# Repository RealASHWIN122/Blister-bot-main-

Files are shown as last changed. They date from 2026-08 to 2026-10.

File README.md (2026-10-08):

# Blister Bot 💊🤖: DIY Edge AI Automated Medicine Dispenser

We can see automated medicine dispensers ranging from simple timed plastic boxes to massive pharmacy robotics. When we generally talk about home dispensers, they usually require the user to manually pop out pills and load them into daily bins. But what if a robot could handle the original packaging directly?

In this project, we challenge ourselves to build a complex mechatronic system that combines rotational indexing with a Cartesian CNC movement to mechanically punch pills right out of their original foil blister packs. Instead of relying on cloud APIs, this robot is powered entirely by Local Edge AI to ensure patient privacy (HIPAA compliance), offline reliability, and low-latency mechanical targeting.

If you're wondering how to make a smart, AI-driven pill dispenser at home using an Arduino Uno Q, this build walks through the full process, from CNC kinematics to the conversational code.

---

## 💡 Motivation
What if you didn't have to manually strip pills from medicine packets every time you had a cold? What if elderly people in nursing homes and living alone at home could be safely monitored and assisted even when there is no one around? And what if all of this was hands-free and handled by speaking as if you were talking to a regular person—and to top it off, all offline, so your private talks remain strictly within your circle?

That's what the Blister Bot is all about.

Not only has AI become more capable, it has also become vastly more efficient. Now, small models that can run on an old laptop with no dedicated GPU can handle complex tasks including conversational chatbots, coding, character recognition, speech-to-text, and facial recognition. All of this opens up the possibilities of creating useful, intelligent devices without needing an internet connection.

Historically, the only limitation was lightweight, powerful, and cheap hardware. We were stuck using TinyML on classic boards like the ESP32 or Arduino Uno R4, which are ultimately just microcontrollers lacking the raw memory to hold complex workflows. Luckily, with the creation of the Arduino Uno Q and similar boards, we finally have the edge hardware to pull off these AI hardware projects without compromise.

---

## 🤖 What is the Blister Bot?
The Blister Bot is a prototype DIY automated medicine dispenser designed to securely manage, schedule, and dispense medication directly from standard foil/plastic blister packs. Unlike traditional automatic dispensers where you must manually extract each pill to load the machine, the Blister Bot takes the entire untouched blister pack. It utilizes a custom-built 3-axis mini CNC machine to scan, target, and plunge the pill out of its casing. 

Furthermore, the Blister Bot acts as an intelligent medical assistant. It features a fully conversational AI interface, allowing patients to simply talk to it. Before dispensing any medication, it uses facial recognition to authenticate the user, cross-referencing their identity with an internal SQLite database to prevent overdosing or dispensing to the wrong patient. All of this runs entirely offline on edge hardware.

---

## ✨ Key Advantages
* **Zero Prep Work:** Dispenses directly from original blister packs using a CNC punch, eliminating the tedious need to pre-sort pills into weekly bins.
* **100% Offline AI:** Uses miniaturized, local AI models (like Qwen 0.5B, Sherpa-ONNX, and Piper) to ensure medical data privacy and zero latency. Absolutely no internet connection is required.
* **Conversational Interface:** Talk to it naturally instead of navigating a complex touchscreen, app, or confusing buttons.
* **Biometric Security:** Prevents accidental or unauthorized overdoses by physically verifying the patient's face before cutting the foil.
* **Dual Monitoring Interfaces:** Both a physical Edge LCD terminal and an Appliance Flask Web UI for caregivers.

---

## 🧰 Components Required

| Parts Used | How Many Units Required | Purpose |
| :--- | :---: | :--- |
| **Arduino Uno Q** | 1 | The main brain. The quad-core Qualcomm side handles AI and web serving, while the ARM Cortex RTOS handles real-time motor control. |
| **ULN2003 Motor Drivers** | 3 | Drives the stepper motors based on GPIO signals from the Uno Q. |
| **28BYJ-48 Stepper Motors** | 3 | Controls the X, Y, and Z axes of the CNC gantry and the rotary wheel indexing. |
| **USB Webcams** | 2 | Camera 1 is for patient Facial Recognition. Camera 2 is for Pill Contour Detection. |
| **16.8V Battery Pack** | 1 | Main power supply for the entire robotic system. |
| **LM2596 Buck Converter** | 1 | Steps down the 16.8V battery voltage to a safe, dedicated 5V rail for the motors. |
| **Custom 3D Printed Parts** | 1 Set | Includes the `blissupport.stl` framing, CNC gantry, and the `medicinewheelstand.stl` rotary wheel. |

---

## ⚡ System Architecture

*(System Architecture Image Placeholder)*
> **Tip:** You can generate this system architecture block diagram using a tool like **Mermaid.js**, **Draw.io**, or **Lucidchart**.
System Architecture Placeholder

The Blister Bot relies on a highly integrated architecture split between logical AI processing and real-time physical actuation:

1. **Conversational LLM Interface 🗣️**
   When you approach the machine, it utilizes a local **Qwen 2.5 LLM (0.5 Billion parameters)** for reasoning.
   * **Listening:** Uses **Sherpa-ONNX** (fine-tuned on custom voice data) for fast, offline speech-to-text.
   * **Processing:** Evaluates commands against an internal SQLite medical schedule and ruleset.
   * **Speaking:** Replies verbally using **Piper** for high-quality text-to-speech.

2. **Facial Recognition Security 👤**
   To prevent unauthorized dispensing, the system requires biometric authentication.
   * Your medical profile is securely stored using an **LBPH (Local Binary Pattern Histogram)** face recognizer.
   * Authentication must pass before the physical CNC actuates.

3. **Automated Pill Extraction ⚙️**
   * Camera 2 takes a snapshot of the blister pack.
   * **OpenCV contour detection** and **Meta's SAM 2 (Segment Anything Model 2)** locate the exact boundaries of the pill.
   * The software calculates a "Mirror Math" coordinate transformation.

---

## 🔌 Circuit Diagram

*(Circuit Diagram Image Placeholder)*
> **Tip:** You can generate professional circuit schematics using tools like **Fritzing**, **KiCad**, or **Tinkercad**.
Circuit Diagram Placeholder

### Power Isolation
To prevent inductive voltage spikes from the stepper motors from browning out or frying the logic board, the system uses an isolated power design. The 16.8V battery pack is connected to an **LM2596 buck converter** to supply a dedicated 5V rail strictly for the ULN2003 drivers and stepper motors. The Arduino Uno Q is powered safely on its own separated circuit.

---

## 📐 3D Printing & Mechanical Design

The mechanical chassis is built around a Cartesian CNC coordinate system paired with a rotary axis.
* **The Rotary Wheel (`medicinewheelstand.stl`):** Holds the foil blister packs. It indexes rotationally to bring the correct medicine pack to the cutting area. The 28BYJ-48 stepper motor is geared to provide high torque for rotating the heavy loaded wheel.
* **The CNC Gantry:** Actuates on the back of the packet to trace, plunge, and drill the pill out of the foil using a specialized punch tool. The gantry relies on dual X/Y rails.
* **The Frame (`blissupport.stl`):** Houses the cameras at fixed focal lengths to ensure OpenCV contour mathematics are consistently accurate.

---

## 💻 Deep Dive: Core AI Capabilities & Software Modules

Because the machine runs offline, memory management on the Uno Q is critical. The state machine (`master_controller.py`) orchestrates loading and unloading AI models dynamically so we don't run out of RAM.

### 1. Dual Interface System
The bot provides two main ways to interact, designed for both patients and caregivers:
* **Appliance Terminal:** A Flask web UI running on port 5000 that allows caregivers to view the live MJPEG camera feed, monitor system logs, and manually trigger HTTP voice commands.
* **Edge Terminal:** A lightweight serial-based interface (`main_edge_terminal.py`) that uses `faster-whisper` for ultra-low latency STT and outputs the AI's responses to a physical LCD screen via a serial bridge connected to the microcontroller's UART port (`/dev/ttyGS0`).

### 2. Fast Audio Processing (STT/TTS)
The voice pipeline is heavily optimized for the embedded CPU of the Arduino Uno Q:
* **Faster-Whisper:** We use the `tiny.en` model with `INT8` quantization via CTranslate2. This allows for 1:1 real-time transcription (a 5-second voice clip transcribes in ~5 seconds).
* **Hardware Resampling:** To prevent "hallucination" bugs common in Whisper when fed distorted audio, we strictly use ALSA hardware resampling (`plughw:0,0`) to convert the USB microphone's native sample rate perfectly to 16000Hz.
* **Edge-TTS & Piper:** For speech synthesis, we rely on low-latency TTS engines that generate human-like voices and play them back instantly via `ffplay`.

### 3. Intelligent Medicine Scanner & RAG
* **Medicine Scanner (OCR):** The appliance terminal uses `rapidocr-onnxruntime` to continuously monitor the camera feed, extract text from medicine packets, and announce the names aloud.
* **Retrieval-Augmented Generation (RAG):** When you ask for medication, the Qwen LLM queries an internal `medical_database.json` to verify schedules, dosages, and interactions before dispensing. This prevents patients from asking for restricted medications at the wrong time.

### 4. Facial Recognition & Security
To ensure medication is dispensed exclusively to the prescribed patient:
* We utilize the **LBPH (Local Binary Pattern Histogram)** recognizer from `opencv-contrib-python-headless`.
* During inference, it cross-references the detected face against a trained dataset of known faces.
* Every dispense event and interaction is strictly logged to an encrypted local SQLite database (`attendance.db`).

### 5. Mirror Math Kinematics & SAM 2 Vision
Locating the pill is a complex physical-to-digital translation problem. 
By looking at the clear plastic bubbles on the front of the packet, Camera 2 takes a snapshot. We use **Meta's Segment Anything Model 2 (SAM 2)** combined with OpenCV to accurately detect the boundaries of the blister. 

The Python script applies a scaling factor to convert pixels to millimeters, and then applies a **Mirror Math** formula to tell the rear-mounted CNC plunger exactly where to strike on the back of the packet:
```python
# The camera looks at the front, but the CNC punch attacks from the rear.
# The X-axis must be inverted for perfect alignment.
X_plunger = X_cam * -1
```

### The Full AI Pipeline
1. **Audio Trigger:** Captured via USB mic (filtered by Voice Activity Detection).
2. **STT:** Transcribes audio to text offline.
3. **LLM & RAG:** Processes intent (e.g. "I need paracetamol") against the medical database.
4. **Face ID:** Verifies the user against `attendance.db` via OpenCV.
5. **Vision:** Targets the pill boundaries using SAM 2.
6. **CNC Drive:** Pulses the stepper motors to mechanically punch the pill.
7. **TTS:** Announces "Your medication is dispensed."

---

## 🛠 Setup & Installation Guide

Setting up the Blister Bot environment locally on the board requires installing a few core edge-AI dependencies:

### Prerequisites
Make sure your Arduino Uno Q is running its Debian Linux image and is connected to Wi-Fi for the initial download phase.
```bash
sudo apt update
sudo apt install python3-pip python3-opencv ffmpeg portaudio19-dev libasound-dev
```

### Model Installations
Install the specialized Edge AI models required for the system to operate:
```bash
pip3 install faster-whisper edge-tts rapidocr-onnxruntime Flask pyserial sounddevice
pip3 install git+https://github.com/facebookresearch/sam2.git
```

### Flashing the Real-Time OS
Remember that the high-level Python code runs on the Qualcomm Quad-Core. You must compile and flash the Arduino `C++` stepper motor code to the ARM Cortex side of the board so that it can receive instructions over the serial bridge from the `cnc_driver.py`.

---

## 📁 Repository Structure

All project files, drivers, and AI scripts are contained within the main repository.

```text
📦 blister-bot
 ┣ 📂 appliance_terminal/          # Flask Web UI, OCR Scanner & HTTP mic triggers
 ┣ 📂 edge_terminal/               # Serial LCD interface & faster-whisper STT
 ┣ 📂 code/
 ┃ ┣ 📜 master_controller.py       # Main state machine & orchestrator
 ┃ ┣ 📜 cnc_driver.py              # Kinematics & tool offsets
 ┃ ┣ 📜 test_stt.py                # Automated testing for finetuned STT
 ┃ ┣ 📜 test_rag.py                # RAG database evaluation scripts
 ┃ ┣ 📜 medical_database.json      # RAG inventory and patient rules
 ┃ ┣ 📜 attendance.db              # SQLite logs for Face ID
 ┃ ┣ 📂 blister_detector/          # Meta SAM 2 vision bounding box scripts
 ┃ ┗ 📂 ai_modules/           
 ┃   ┣ 📜 face_id.py               # LBPH Face Recognizer
 ┃   ┣ 📜 vision.py                # OpenCV contour detection & SAM 
 ┃   ┗ 📜 conversational.py        # Qwen, Sherpa, and Piper loops
 ┣ 📂 scripts/
 ┃ ┣ 📜 deploy_master.sh           # Automated deployment scripts
 ┃ ┗ 📜 rsync.exp                  # Edge syncing
 ┣ 📂 cad/                         # 3D printable STL files
 ┣ 📂 docs/                        # Weekly progress logs
 ┗ 📜 README.md
```

---

## 🎯 Testing & Final Result

*(Video/GIF Placeholder)*
Final Result Video Placeholder

Once completely assembled, the Blister Bot operates entirely hands-free. A patient simply requests their medicine, looks into the primary camera, and waits. The machine indexes the wheel, lines up the CNC plunger, and perfectly extracts the pill directly from the foil without any human intervention.

---

## 🚀 Running the Bot

To start the Blister Bot system on the Arduino Uno Q, navigate to the `code/` directory and run the main state machine script:
```bash
cd code/
python3 master_controller.py
```

*Note: Alternatively, you can use the `scripts/deploy_master.sh` script to set up `systemd` services so the bot runs automatically on boot.*

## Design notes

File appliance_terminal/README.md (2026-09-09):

# Blister-Bot Appliance Terminal

The Appliance Terminal is a Flask-based AI system designed to run on the **Arduino Uno Q**. It transforms the board into an intelligent medicine-scanning assistant featuring Optical Character Recognition (OCR), Face Recognition, and an ultra-fast Voice Assistant (Speech-to-Text & Text-to-Speech).

## Core Features

### 1. Medicine Scanner (OCR)
- Uses `rapidocr-onnxruntime` to continuously monitor the camera feed.
- Extracts text dynamically from medicine packets and displays the detected text on the web interface.
- Automatically reads the detected medicine names out loud using the TTS engine.

### 2. Lightning-Fast Voice Assistant (STT & TTS)
The voice pipeline was heavily optimized for the embedded CPU of the Arduino Uno Q:
- **Speech-to-Text (STT)**: 
  - Upgraded from HuggingFace `transformers` to **`faster-whisper`** (powered by `CTranslate2`).
  - Uses `INT8` quantization and the `tiny.en` model to achieve blistering fast **1:1 real-time transcription** (a 5-second voice clip transcribes in ~5 seconds).
  - Implements **ALSA hardware resampling** (`plughw:0,0`) to perfectly convert the USB microphone's native sample rate to the strictly required `16000Hz`. This completely eliminates the "hallucinations" (random ghost phrases) that Whisper models often produce when fed distorted audio.
  - Automatically filters out silence using `faster-whisper`'s advanced Voice Activity Detection (VAD).
- **Text-to-Speech (TTS)**:
  - Uses `edge-tts` to generate natural-sounding speech and `ffplay` to play it immediately through the audio output.
  - The appliance automatically repeats what you say when the microphone is manually triggered, and reads out scanned text.

### 3. Face Recognition & Attendance
- Utilizes OpenCV (`opencv-contrib-python-headless`) with Haar cascades and the `LBPHFaceRecognizer`.
- Detects faces and cross-references them against a trained dataset (`known_faces`).
- Logs attendance and interactions to a local SQLite database (`attendance.db`).

### 4. Flask Web Interface
- The entire system is hosted locally via Flask on port `5000`.
- Serves the live camera feed (MJPEG streaming).
- Provides a `/trigger_mic` REST endpoint to manually initiate a 5-second voice recording and transcription.

## Deployment & Setup

The system is deployed to the Arduino Uno Q using the `setup_appliance.sh` script located in the project root. The setup script performs the following fully automated tasks:

1. **Space Management**: Cleans up unused files (e.g., old Ollama models) on the board's filesystem.
2. **File Transfer**: Uses `scp` to push `appliance.py`, the `attendance.db`, and the face datasets directly to the board.
3. **Dependency Installation**: Installs the optimized dependency stack globally (`--break-system-packages`) including `faster-whisper`, `rapidocr-onnxruntime`, `Flask`, `edge-tts`, and `opencv`.
4. **Systemd Service**: Creates and enables `appliance.service` so the AI terminal automatically starts silently in the background on boot.

## How to Test the Microphone
1. Ensure the board is powered and connected to the network.
2. Open the web interface at `http://<ARDUINO_IP>:5000`.
3. Wait ~10 seconds for the `faster-whisper` model to silently load in the background.
4. Click the **"🎤 Speak"** button, talk into the USB mic for 5 seconds, and watch the text appear on the screen and echo back to you.

## Recent Migrations
- **Migrated away from `transformers`**: Swapping to `faster-whisper` reduced STT processing time by an order of magnitude. An attempt to use `base.en` was made, but the 45-second latency was unacceptable for a voice assistant. Reverting to `tiny.en` within `faster-whisper` solved all latency issues while maintaining VAD accuracy.
- **ALSA `plughw` fix**: Swapped `hw:0,0` for `plughw:0,0` in the `arecord` command to allow the Linux kernel to handle audio resampling, preventing severe Whisper hallucination bugs.

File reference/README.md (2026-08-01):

# Week 1: Intelligent Edge-AI Medicine Dispenser ("Blister Bot")






Welcome to the **Week 1** repository module for **Blister Bot** (Intelligent Edge-AI Medicine Dispenser). This directory contains all technical specifications, 3D CAD/Blender models, interactive WebGL 3D web applications, MP4 video animation demonstrations, Python vision mappers, C++ STM32 MCU firmware sketches, and publication-ready PDF documentation reports generated during Week 1.

---

## 📌 Executive Project Summary

**Blister Bot** is an autonomous, fully offline healthcare dispenser. Unlike conventional pill organizers that require manual sorting into plastic compartments or cloud dependence, Blister Bot operates as an edge-AI healthcare assistant built on the dual-processor **Arduino UNO Q** board (Qualcomm Dragonwing QRB2210 Linux MPU + STM32U585 MCU).

### Core Innovation: Non-Destructive Deblistering
Rather than high-force mechanical punching that crushes fragile pills, Blister Bot utilizes a two-stage mechanism:
1. **270-Degree U-Shaped Foil Scoring**: A motorized rotary cutter wheel scores a 270° U-shaped arc through the aluminum foil backing, creating a hinged flap while leaving the top 90° edge connected.
2. **Soft Silicone Plunger Pin Ejection**: A spring-loaded silicone plunger pin gently pushes against the transparent front PVC bubble, guiding the capsule tablet out through the pre-scored flap into the delivery chute.

---

## 📂 Week 1 File Navigation & Directory Structure

```
Week 1/
├── README.md                             # Navigation guide for GitHub repository (this file)
├── Project Blueprint.pdf                 # Original technical specification document
├── blueprint_text.txt                    # Plaintext extraction of Project Blueprint PDF
├── Week1_Documentation.md               # Main Week 1 technical markdown documentation
├── Week1_Documentation.pdf               # Publication-ready PDF documentation report (2.98 MB)
├── generate_pdf_report.py                # Python script to compile Week1_Documentation.pdf
│
├── blister_bot.blend                     # Native 3D Blender model file for complete Blister Bot
├── create_blister_bot_model.py           # Blender Python script generating full 3D appliance & renders
│
├── frames/                               # Extracted visual reference frames from reference video
│   ├── frame_000.jpg ... frame_009.jpg
│
├── renders/                              # High-resolution rendered 3D preview images
│   ├── render_perspective.png            # Studio isometric view
│   ├── render_mechanism.png              # Internal 2-axis CNC gantry close-up
│   └── render_front.png                  # Front presentation view
│
├── scoring mechanism/                    # Horizontal Scoring & Ejection Mechanism Module
│   ├── 3d_cutting_animation.html         # Interactive 3D WebGL (Three.js) animation web app
│   ├── scoring_mechanism_demo.mp4        # 120-frame MP4 video animation demonstration
│   ├── scoring_mechanism.blend           # Specialized Blender 3D kinematic model file
│   ├── Scoring_Mechanism_Report.pdf      # Dedicated PDF technical report (4.61 MB)
│   ├── Scoring_Mechanism_DeepDive.md     # Markdown technical deep-dive report
│   ├── deblister_vision_mapper.py        # Python front-to-back coordinate transformation & U-trajectory mapper
│   ├── scoring_gantry_controller.ino     # STM32 C++ firmware sketch for 2-axis CNC stepper & plunger
│   ├── animate_scoring_mechanism.py      # Blender Python animation generator
│   ├── compile_scoring_video.py          # Blender PNG frame renderer
│   ├── encode_mp4.py                     # OpenCV MP4 video encoder
│   ├── scoring_toolhead.png              # Still render preview (Step 1)
│   ├── u_flap_scored.png                 # Still render preview (Step 2)
│   └── tablet_ejection.png               # Still render preview (Step 3)
│
└── vertical scoring mechanism/           # Vertical Strip Plunger Ejection Mechanism Module
    ├── vertical_strip_plunger_animation.html # Interactive 3D WebGL (Three.js) animation web app
    ├── vertical_strip_ejection_demo.mp4   # 120-frame MP4 video animation demonstration
    ├── vertical_scoring_mechanism.blend   # Specialized Blender 3D model file (vertical strip orientation)
    ├── Vertical_Scoring_Report.pdf        # Dedicated PDF technical report (1.79 MB)
    ├── animate_vertical_scoring.py        # Blender Python animation generator
    ├── encode_vertical_mp4.py             # OpenCV MP4 video encoder
    ├── generate_vertical_pdf.py           # Python script compiling Vertical_Scoring_Report.pdf
    ├── vertical_strip_toolhead.png        # Still render preview (Phase 1)
    ├── vertical_u_flap.png               # Still render preview (Phase 3)
    └── vertical_plunger_eject.png         # Still render preview (Phase 5)
```

---

## 🚀 Key Modules & How to Use Them

### 1. Interactive 3D WebGL Web Applications (No Blender Required!)
Experience realistic 3D animations directly inside any web browser with orbit controls, step-by-step kinematic phase controls, X-Ray mode, and live telemetry:

- **Horizontal Scoring App**: Open `scoring mechanism/3d_cutting_animation.html` in your web browser.
- **Vertical Strip Plunger App**: Open `vertical scoring mechanism/vertical_strip_plunger_animation.html` in your web browser.

### 2. Video Demonstrations (MP4 Renders)
- **Horizontal Scoring Demo**: `scoring mechanism/scoring_mechanism_demo.mp4`
- **Vertical Strip Plunger Demo**: `vertical scoring mechanism/vertical_strip_ejection_demo.mp4`

### 3. PDF Documentation Reports
- **Week 1 Master Report**: `Week1_Documentation.pdf` (2.98 MB)
- **Horizontal Mechanism Deep-Dive**: `scoring mechanism/Scoring_Mechanism_Report.pdf` (4.61 MB)
- **Vertical Mechanism Deep-Dive**: `vertical scoring mechanism/Vertical_Scoring_Report.pdf` (1.79 MB)

### 4. Software & Firmware Source Code
- **Python Vision Coordinate Mapper**: `scoring mechanism/deblister_vision_mapper.py`  
  *Transforms camera pixel coordinates \((X_{\text{pixel}}, Y_{\text{pixel}})\) to rear aluminum foil gantry space \((X_{\text{gantry}}, Y_{\text{gantry}})\) and calculates 270° U-trajectory waypoints with dynamic safety clearance buffers (\(R_{\text{cut}} = R_{\text{pill}} + 2.0\text{mm}\)).*
- **STM32 Microcontroller Firmware**: `scoring mechanism/scoring_gantry_controller.ino`  
  *Arduino C++ sketch driving X/Y stepper motors smoothly via `AccelStepper`, engaging the rotary cutter wheel solenoid, actuating the silicone plunger pin, and verifying tablet drop via IR optic sensors.*

### 5. Blender 3D CAD & Kinematic Models
To open or re-render 3D models in Blender 5.2 LTS:
```bash
# Re-create and render full Blister Bot appliance model
blender --background --python create_blister_bot_model.py

# Re-create and render horizontal scoring mechanism
blender --background --python "scoring mechanism/compile_scoring_video.py"

# Re-create and render vertical strip mechanism
blender --background --python "vertical scoring mechanism/animate_vertical_scoring.py"
```

---

## 🛠️ Technology Stack & Dependencies

| Tool / Library | Version / Domain | Purpose |
| :--- | :--- | :--- |
| **Blender** | 5.2.0 LTS | 3D CAD modeling, PBR shading, studio lighting, camera tracking, and animation. |
| **Three.js** | r128 (WebGL) | Interactive 3D web application rendering, PBR materials, orbit controls, spark effects. |
| **Python** | 3.13 | Vision mapping mathematics, coordinate transformation, OpenCV video encoding, PDF report building. |
| **OpenCV (`cv2`)** | 4.x | Video frame sequence assembly and MP4 encoding. |
| **ReportLab** | 5.0.0 | Programmatic PDF document compilation with custom styling, tables, and images. |
| **Arduino C++** | STM32 Core | Real-time non-blocking stepper motor control (`AccelStepper.h`) and solenoid actuation. |

---

## 📄 License & Attribution

This project is part of the **Blister Bot** open-hardware healthcare initiative. All 3D models, code, firmware sketches, and documentation in this folder are prepared for open community research and development.

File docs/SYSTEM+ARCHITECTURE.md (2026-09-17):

when the arduino uno q boots up,it first has to search if its connected to all the necessary devices(cams,mic) and also check bluetooth(the speaker for the llm output tts),Then,it needs to use the speaker to say"hi,im awake."

once that happens,if the bot is being used for the first time,the user has to say "bot,setup",in order to start setting up users.the device then outputs "phone or voice" through the speaker(tts),and waits for the users reply("phone or voice")

if phone:
........

if voice:
device asks to define caretakers,each caretaker needs a name,and a time of work(morning,evening,full day),and if the caretaker itself is the patient.facial scanning and adding to the database will be done in parallel using cam1
if the last sentence is false:
after defining each caretaker,the device will ask if the list of caretakers is over,to which the user has to reply yes or no.
if no ,this repeats

if the last sentence is true,skip to patient definition,then go back to the caretaker loop

after the caretaker process is done,the device outputs:"enter patient name:",and waits for the users reply.also scans their face to store in the database
and also asks for age,gender,health issues,medicines to take along with their time(morning/evening,before food/after food),caretaker assigned to which the user can either reply in one word answers or can respond in a couple of sentences,whose meaning and relevant data will be extracted by the llm,and then sqlite tables will be created for everyone
.device asks if there are more patients,user replies yes/no
if yes,repeat
if no,break

this ends part1 of setup mode

in part2 of setup mode
the user has to insert the meds,after the user verbally confirms that all the meds have been inserted,the device uses cam 2 to scan each med text to dermine med name,dosage etc.it will have a separate table containing info related to mediicnes,so it will cross check it with this if its either unable to read the ocr small text or just to double check.the count of each medicines will also be stored alongisde

this ends setup mode

normal running mode:
after setup mode has been finished,the device will work normally.it will speak and alert the users using the speaker to alert people when they have to take their medicines.when the user walks in front of the camera or speaks near the mic,the facial recognition tool will work and scan the user to see if its a previously established user.if its a patient,the device will ask if they have had food (if they have special post food meds) and the same for if they have pre food meds.if they havent had food,then the device will them to eat their food and come back.if its a caretaker,they will be asked about whuch patient they are attending for,and the steps proceed as above.Once the conditions are met,the mediicnes are cut and dispensed using the motors.the wheel isrorated until the correct med comes in view,cam 2 is used to identify where the boundaries need to be drawn using the sam2 model,and then the motors are drawn along these boundaries.first the z motor or thrusting motor is thrust into the boundary,and then the xy gantry is used to create a hole arounf the med.then,the med holder is rotated by exactly enough degrees so that the cut med is facing the ground and it falls off.repeat if there are other meds.
update the med counter for all the meds,if n(one specific med)=1,alert user using speaker,and store reminder and alert the next dispensing timeslot right before dispensing the medicines

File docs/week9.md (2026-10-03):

# Week 9: Speech-to-Text Customization & RAG Integration

During Week 9 (Sep 22 - Sep 28), we focused heavily on resolving the poor performance of the baseline STT model and began prototyping LLM RAG functionality.

## Accomplishments
- **Custom STT Dataset Collection**: Built a full Flask-based web application (`code/stt_dataset_collector/app.py`) to systematically record, manage, and label custom audio phrases.
- **Catastrophic Forgetting Mitigation**: Successfully fine-tuned the Zipformer STT model on 91 custom audio samples using the `icefall` framework. To prevent the model from collapsing (catastrophic forgetting), we strategically froze the acoustic encoder and only trained the decoder and joiner.
- **STT Evaluation**: Automated STT evaluation metrics with `test_stt.py`, confirming massive improvements in recognizing specific medical intents (e.g., "what medicines do we have").
- **LLM RAG Pipeline**: Integrated Retrieval-Augmented Generation capabilities into `master_controller.py`, allowing the Qwen LLM to query and answer questions about patients and inventory. Built and tested this via `code/test_rag.py` and `code/test_rag_auto.py`.
- **Qualcomm AI Hub / Deployment**: Set up compilation scripts (`compile_qwen_aihub.py`) for optimized hardware inference and moved automated deployment shell scripts into `scripts/` to keep the repo clean.

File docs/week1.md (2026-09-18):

# Week 1: Initial Mechanical Design & Ideation

During Week 1 (July 28 - Aug 3), we laid the groundwork for the mechanical operation of the Blister Bot.

## Accomplishments
- Explored 3D models and animations to visualize how a machine could automatically punch a pill out of a blister pack.
- Documented initial CAD and scoring ideas.
- Designed early iterations of the scoring mechanisms (cutting the foil before plunging).

All historical files from Week 1 (Blender models, animations, old reports) are archived in [reference/week1/](../reference/week1/).

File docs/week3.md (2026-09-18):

# Week 3: Face Recognition & Arduino Preparations

During Week 3 (Aug 11 - Aug 17), we began exploring how to physically control our bot, alongside experiments with adding facial recognition for patient security.

## Accomplishments
- **Arduino Setup**: Started the initial Arduino firmware logic to interact with motors.
- **Face Recognition**: Explored basic LBPH face recognition for patients using `facerecogjith`.
- **Database Setup**: Initialized the SQLite database schemas to hold attendance and patient medical details.

All historical files from Week 3 are archived in [reference/week3/](../reference/week3/).

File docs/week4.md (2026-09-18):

# Week 4: Edge AI Prototyping

During Week 4 (Aug 18 - Aug 24), we explored numerous AI models in isolation to determine what would be viable on our edge computing device (Uno Q).

## Accomplishments
- **OCR Modules**: Evaluated text extraction mechanisms for reading blister pack labels.
- **Speech Models**: Built `texttospeech` and `speechtotext` standalone scripts to test offline inference speeds.
- **Action Recognition**: Tested the Edge Impulse action recognition platform (`action-recog-applab`).
- **Hardware Inspiration**: Sourced and reviewed the `Arduino mini CNC plotter` project as a mechanical base for our drilling mechanism.

All historical files from Week 4 are archived in [reference/week4/](../reference/week4/).

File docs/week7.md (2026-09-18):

# Week 7: Architecture Integration

During Week 7 (Sep 8 - Sep 14), we began integrating our standalone hardware tests and web apps into a cohesive software architecture.

## Accomplishments
- **CNC Controller**: Built the `stepper_motor_controller` Flask app and the underlying Arduino logic to handle web-based 3-axis control.
- **Remote Tooling**: Implemented `ssh_cmd.py`, `sync.py`, and `monitor_viewer.py` to seamlessly deploy code to our remote Uno Q board.
- **Hardware Finalization**: Produced the first versions of our finalized `.stl` files for the physical structure of the bot.

Deprecated tests, temporary Streamlit apps, and intermediate deployment scripts from Week 7/8 are archived in [reference/week7_8/](../reference/week7_8/). All finalized tooling is stored in `code/`.

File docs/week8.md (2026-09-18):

# Week 8: Master Controller & Final System

During Week 8 (Sep 15 - Sep 21), we brought everything together to form the autonomous Blister Bot.

## Accomplishments
- **Master Controller**: Developed `master_controller.py`, which integrates our offline LLM (Qwen), Speech-to-Text (Sherpa-ONNX), Text-to-Speech (Piper), and OpenCV Pill detection.
- **Dynamic CNC Integration**: Merged the CNC controller so the bot can verbally request pills, visually detect their boundary contours, and instruct the gantry to physically pierce and trace the boundary to extract them.
- **Final Hardware Architecture**: Finalized the remaining CAD support files (like `blissupport.stl` and `medicinewheelstand.stl`) which are stored directly in the root `cad/` directory.

The finalized, working system is contained entirely inside the `code/` folder.

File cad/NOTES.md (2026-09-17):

# Packet paddle wheel

- Single integrated rotor; Z is the hub axis. Four blades repeat at 90°.
- Blade length 95 mm parallel to Z; base thickness exactly 3 mm. Outer blade width 68 mm includes two 2 mm rail walls, with exactly 64 mm between the internal vertical walls.
- Each centered rectangular window is 50 × 80 mm, through the base. Centering leaves 7.5 mm flush end borders. The loading-end border is not raised and does not block axial sliding; an entirely absent entry border would require an additional notch or a non-centered/open-ended window.
- Loading is from Z=0 toward the raised stop at Z=93–95 mm. Each pair of inward-facing channels has 2 mm retaining lips and 3.5 mm clearance above the base; top opening between lips is 60 mm. No raised transverse loading-end obstruction.
- Assumed hub Ø20 × 97 mm (Z=-1 to 96 mm), rail height 5 mm above base, wall thickness 2 mm, lip thickness 1.5 mm.
- Socket: nominal Ø5 mm circle truncated at X=1.5 mm (4 mm from flat to opposite circular extreme); blind depth 12 mm from Z=-1. No fit allowance added. Verify flat and clearance against the actual motor shaft before fabrication.
- Rectangle profiles share a dimension-driven helper function because the same construction repeats at differing sizes. Its sketches are not point-and-click editable; dimensions remain editable in source.
- Validation: all seven evaluated solver sketches fully constrained; lint passed; rendered overview and close-ups verified windows, guide entrances, stops, and D-shaped cavity.

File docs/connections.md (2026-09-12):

# CNC Plotter Hardware Connections

This document details the complete hardware wiring between the Arduino Uno Q, the breadboard, the stepper motor drivers, and the power supply.

## 1. Breadboard & Power Supply Connections
> [!WARNING]
> Never power the stepper motors directly from the Arduino Uno Q's 5V pin! They draw too much current and will damage the board.

* **External Power Supply (+):** Connect the positive wire from your isolated 6V (4x AA) battery pack to the positive (red) rail on the breadboard.
* **External Power Supply (- / GND):** Connect the negative wire from your 6V (4x AA) battery pack to the negative (blue/black) rail on the breadboard.
* **Arduino Uno Q GND:** Connect a wire from any `GND` pin on the Arduino Uno Q to the negative (blue/black) rail on the breadboard. **This common ground is critical.**

## 2. Stepper Motor Drivers (e.g., ULN2003)
Each of the 3 motors requires its own driver board. 

### Powering the Drivers:
For **all three** drivers (X, Y, and Z):
* Connect the **`+` or `VCC`** pin on the driver to the positive rail on the breadboard.
* Connect the **`-` or `GND`** pin on the driver to the negative rail on the breadboard.

### Plugging in the Motors:
* Plug the white plastic connector coming from the X-Axis stepper motor directly into the white socket on the X-Axis driver board.
* Plug the Y-Axis stepper motor into the Y-Axis driver board socket.
* Plug the Z-Axis stepper motor into the Z-Axis driver board socket.

---

## 3. Arduino Data Connections (IN1, IN2, IN3, IN4)

Connect the logic pins from the Arduino Uno Q to the inputs on each respective driver board:

### X-Axis Motor Driver (Stepper 1)
* **IN1** $\rightarrow$ Arduino Pin `2`
* **IN2** $\rightarrow$ Arduino Pin `3`
* **IN3** $\rightarrow$ Arduino Pin `4`
* **IN4** $\rightarrow$ Arduino Pin `5`

### Y-Axis Motor Driver (Stepper 2)
* **IN1** $\rightarrow$ Arduino Pin `6`
* **IN2** $\rightarrow$ Arduino Pin `7`
* **IN3** $\rightarrow$ Arduino Pin `8`
* **IN4** $\rightarrow$ Arduino Pin `9`

### Z-Axis Motor Driver (Stepper 3)
* **IN1** $\rightarrow$ Arduino Pin `10`
* **IN2** $\rightarrow$ Arduino Pin `11`
* **IN3** $\rightarrow$ Arduino Pin `12`
* **IN4** $\rightarrow$ Arduino Pin `13`

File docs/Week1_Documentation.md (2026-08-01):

# Week 1 Documentation: Intelligent Edge-AI Medicine Dispenser ("Blister Bot")

## 1. Executive Summary & Project Vision

The **Intelligent Edge-AI Medicine Dispenser ("Blister Bot")** is an autonomous, fully offline healthcare system. Unlike conventional pill organizers that require tedious manual sorting or cloud connectivity, Blister Bot operates as an intelligent healthcare assistant. It directly interprets written prescriptions via computer vision (OCR), converses naturally with patients via a localized Large Language Model (LLM), prevents accidental overdoses, and **mechanically extracts medications directly from uncut aluminum blister strips**.

---

## 2. Hardware Architecture & Technical Specifications

The system is built upon the dual-processor architecture of the **Arduino UNO Q** (Qualcomm Dragonwing QRB2210 + STM32U585 MCU):

| Subsystem Component | Hardware / Software | Primary Responsibilities |
| :--- | :--- | :--- |
| **Linux MPU** | Qualcomm Dragonwing QRB2210 | Localized LLM (`llama.cpp` + `TinyLlama`), Voice STT (`Whisper.cpp`), Prescription OCR, Face Recognition, Action Tracking (`MediaPipe`), Database management. |
| **Microcontroller (MCU)** | STM32U585 MCU | Real-time 2-axis CNC gantry motor control (`AccelStepper`), sensor monitoring, safety interlocks, and closed-loop dispensing verification. |
| **Smart Interface** | 7" Portrait TFT/LCD Touchscreen | Displays pill schedules, visual dosage cross-checks, consumption graphs, and system telemetry. |
| **Vision Sensor** | Integrated HD Camera Module | Patient face recognition authentication, pill identification, prescription scanning, and hand-to-mouth action verification. |

---

## 3. Visual Reference Breakdown (From Video Reference)

Analysis of the reference video (`WhatsApp Video 2026-07-20 at 10.29.20 PM.mp4`) revealed the core architectural and mechanical design parameters:

````carousel
![Reference Frame 002: Dual Chamber & Smart Touch Display](file:///c:/FARIS/Blister%20Bot/Blister-bot-main-/Week%201/frames/frame_002.jpg)
<!-- slide -->
![Reference Frame 005: Internal Deblistering CNC Gantry & U-Scoring](file:///c:/FARIS/Blister%20Bot/Blister-bot-main-/Week%201/frames/frame_005.jpg)
<!-- slide -->
![Reference Frame 008: Appliance Presentation Overview](file:///c:/FARIS/Blister%20Bot/Blister-bot-main-/Week%201/frames/frame_008.jpg)
````

### Key Design Insights Extracted:
1. **Dual-Chamber Enclosure**: Left side houses illuminated internal mechanical components behind a transparent acrylic door; right side features the smart touch interface, AI camera, and dispensing tray.
2. **2-Axis CNC Deblistering Gantry**: Precision X/Y motion system carrying a specialized toolhead with a motorized 270-degree rotary cutter wheel and soft silicone plunger.
3. **U-Shaped Scoring Mechanics**: Rather than high-force punching which damages fragile tablets, the tool scores a 270-degree hinged flap in the aluminum foil backing, allowing a soft plunger to push the pill into the chute.

---

## 4. Week 1 3D Model Development & Blender Implementation

A complete, fully detailed 3D model of Blister Bot was procedurally created in **Blender 5.2 LTS** using a Python script (`create_blister_bot_model.py`).

### 3D Render Gallery

```carousel
![3D Render: Isometric Perspective Studio View](file:///c:/FARIS/Blister%20Bot/Blister-bot-main-/Week%201/renders/render_perspective.png)
<!-- slide -->
![3D Render: Deblistering Mechanism Close-Up](file:///c:/FARIS/Blister%20Bot/Blister-bot-main-/Week%201/renders/render_mechanism.png)
<!-- slide -->
![3D Render: Front Presentation View](file:///c:/FARIS/Blister%20Bot/Blister-bot-main-/Week%201/renders/render_front.png)
```

---

## 5. Summary of Built Components in 3D Model

1. **Appliance Body**:
   - Curved-corner desktop enclosure in matte white ABS plastic with dark metallic accents.
   - Hollowed-out left cavity equipped with warm top LED light strip (`Mat_LED_Warm`) and cyan vertical status light bar (`Mat_LED_Cyan`).
   - Beveled acrylic transparent front window door with metallic handle.

2. **Smart Touch Display & Vision Module**:
   - 7" portrait display screen with customized UI overlay (header bar, blister schedule card, action button).
   - Top camera module housing with optical ring and glass lens.
   - Lower RGB LED status indicator bar and sliding pill collection drawer.

3. **Core Deblistering Mechanics**:
   - **Blister Pack Rack**: Multi-slot holder containing aluminum foil cards, transparent PVC bubble pockets, and dual-tone blue/white capsules (`Mat_Pill_Blue`, `Mat_Pill_White`).
   - **2-Axis CNC Gantry**: Upper/lower X aluminum extrusions, vertical Y lead screw, guide rod, and dual NEMA 17 stepper motors (`Mat_Stepper_Body`).
   - **Scoring & Plunger Toolhead**: Motorized rotary steel cutter disc and spring-loaded silicone plunger pin positioned above the funneled delivery chute.

---

## 6. Week 1 Deliverables & File Directory Structure

All files created during Week 1 are organized cleanly in the `Week 1` directory:

```
c:/FARIS/Blister Bot/Blister-bot-main-/
├── LICENSE
├── README.md
└── Week 1/
    ├── Project Blueprint.pdf          # Full technical requirements specification
    ├── WhatsApp Video 2026-07-20...   # Video reference file
    ├── blueprint_text.txt             # Extracted text from PDF blueprint
    ├── create_blister_bot_model.py    # Python procedural 3D model generator for Blender 5.2
    ├── blister_bot.blend              # Native Blender 3D project model file
    ├── Week1_Documentation.md         # Comprehensive documentation report
    ├── frames/                        # Extracted reference frames (frame_000.jpg - frame_009.jpg)
    └── renders/                       # High-resolution rendered 3D preview images
        ├── render_perspective.png
        ├── render_mechanism.png
        └── render_front.png
```

---

## 7. Next Steps & Week 2 Roadmap

1. **Kinematic Animation in Blender**: Animate the 2-axis gantry movement, rotary cutter U-scoring path, and plunger ejection sequence.
2. **CAD Model Refinement**: Export 3D components to STL/STEP formats for parametric 3D printing tolerance checks.
3. **App Lab Firmware Integration**: Prototype basic STM32 C++ motor sketches using `AccelStepper` and Python RPC state machine logic.

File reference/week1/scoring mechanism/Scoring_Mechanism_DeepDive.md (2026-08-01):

# Deep Dive Technical Documentation: Strip Scoring & Tablet Ejection Mechanism

## 1. Overview & Mechanical Philosophy

In conventional automated pill dispensers, medication extraction relies on high-force mechanical punching through uncut blister packs. This brute-force approach frequently causes fragile tablets (e.g., uncoated aspirin, sublingual wafers, or softgel capsules) to fracture, crumble, or burst.

**Blister Bot** solves this through a non-destructive two-stage mechanism:
1. **270-Degree U-Shaped Foil Scoring**: A motorized rotary cutter wheel scores a 270° U-shaped arc through the opaque aluminum foil backing, creating a hinged flap while leaving the top edge connected.
2. **Soft Silicone Plunger Ejection**: A spring-loaded silicone plunger pin gently pushes against the transparent front PVC bubble, guiding the tablet out through the pre-scored foil flap without touching or scratching the medication.

---

## 2. Step-by-Step Kinematic Sequence

```mermaid
flowchart TD
    A["Camera Scans Transparent Front Bubble (X_pixel, Y_pixel)"] --> B["Front-to-Back Coordinate Transformation (X_gantry, Y_gantry)"]
    B --> C["Calculate 270° U-Scoring Path (R_cut = R_pill + 2.0mm)"]
    C --> D["2-Axis CNC Gantry Moves Toolhead to Approach Corner P1"]
    D --> E["Engage Motorized Rotary Cutter Wheel onto Foil"]
    E --> F["Execute U-Path Scoring: P1 -> P2 -> P3 -> P4"]
    F --> G["Disengage Cutter Wheel (270° Hinged Flap Opened)"]
    G --> H["Position Soft Silicone Plunger Pin over Pill Center"]
    H --> I["Extend Plunger 12mm to Push Tablet Through Flap"]
    I --> J["Closed-Loop Optic Beam Break Verification in Delivery Chute"]
```

---

## 3. Mathematical Coordinate & Clearance Equations

### Front-to-Back Coordinate Transformation
The front camera observes transparent PVC bubbles in image pixel space. The transformation to rear aluminum gantry millimeter coordinates is given by:

\[X_{\text{gantry}} = (X_{\text{pixel}} \times S_x) + O_x\]
\[Y_{\text{gantry}} = (Y_{\text{pixel}} \times S_y) + O_y\]

Where:
- \(S_x, S_y\): Scale calibration factors (\(\approx 0.45\text{ mm/pixel}\))
- \(O_x, O_y\): Physical offset between camera optical center and gantry home origin

### Dynamic Safety Clearance Margin
To guarantee the rotary cutter blade never comes into physical contact with the medication:

\[R_{\text{cut}} = R_{\text{pill}} + \Delta_{\text{safety}}\]

Where \(\Delta_{\text{safety}} = 2.0\text{ mm}\).

### 270-Degree U-Flap Trajectory Waypoints
For a target pill centered at \((X_c, Y_c)\), the cutter traverses the following four waypoints:
1. **P1 (Top-Left Approach)**: \((X_c - R_{\text{cut}}, Y_c + R_{\text{cut}})\)
2. **P2 (Bottom-Left Corner)**: \((X_c - R_{\text{cut}}, Y_c - R_{\text{cut}})\)
3. **P3 (Bottom-Right Corner)**: \((X_c + R_{\text{cut}}, Y_c - R_{\text{cut}})\)
4. **P4 (Top-Right Corner)**: \((X_c + R_{\text{cut}}, Y_c + R_{\text{cut}})\)

*The top horizontal segment between P4 and P1 remains un-cut (90° open angle), forming the flexible aluminum hinge.*

---

## 4. Hardware & Software Component Integration

| Component | Role in Scoring & Ejection | Implementation |
| :--- | :--- | :--- |
| **Rotary Cutter Wheel** | 270-degree foil scoring | Motorized dark steel cutting disc driven by gantry toolhead |
| **Silicone Plunger Pin** | Gentle tablet ejection | Soft orange silicone pin actuated by 12mm stroke solenoid |
| **2-Axis CNC Gantry** | X/Y motion positioning | NEMA 17 steppers driven by STM32 MCU (`AccelStepper.h`) |
| **Vision Mapper** | Target coordinate calculation | Python module (`deblister_vision_mapper.py`) |
| **Firmware Controller** | Real-time motion execution | Arduino C++ sketch (`scoring_gantry_controller.ino`) |
| **3D Kinematic Model** | Visual simulation & validation | Blender 5.2 model (`scoring_mechanism.blend`) |
| **Video Demonstration** | Animated sequence breakdown | MP4 video render (`scoring_mechanism_demo.mp4`) |

---

## 5. File & Asset Directory (`scoring mechanism/`)

```
c:/FARIS/Blister Bot/Blister-bot-main-/Week 1/scoring mechanism/
├── deblister_vision_mapper.py       # Python coordinate transformer & U-trajectory mapper
├── scoring_gantry_controller.ino    # STM32 C++ firmware sketch for CNC gantry & plunger
├── animate_scoring_mechanism.py     # Blender 5.2 Python script generating 3D model & video
├── scoring_mechanism.blend          # Specialized Blender 3D model file
├── scoring_mechanism_demo.mp4       # Rendered MP4 animation video sequence
├── Scoring_Mechanism_DeepDive.md    # Technical deep-dive documentation (this file)
├── Scoring_Mechanism_Report.pdf     # Publication-ready PDF document report
├── scoring_toolhead.png             # Frame 25: Toolhead approach render
├── u_flap_scored.png                # Frame 80: 270° U-flap scored render
└── tablet_ejection.png              # Frame 105: Soft plunger tablet ejection render
```

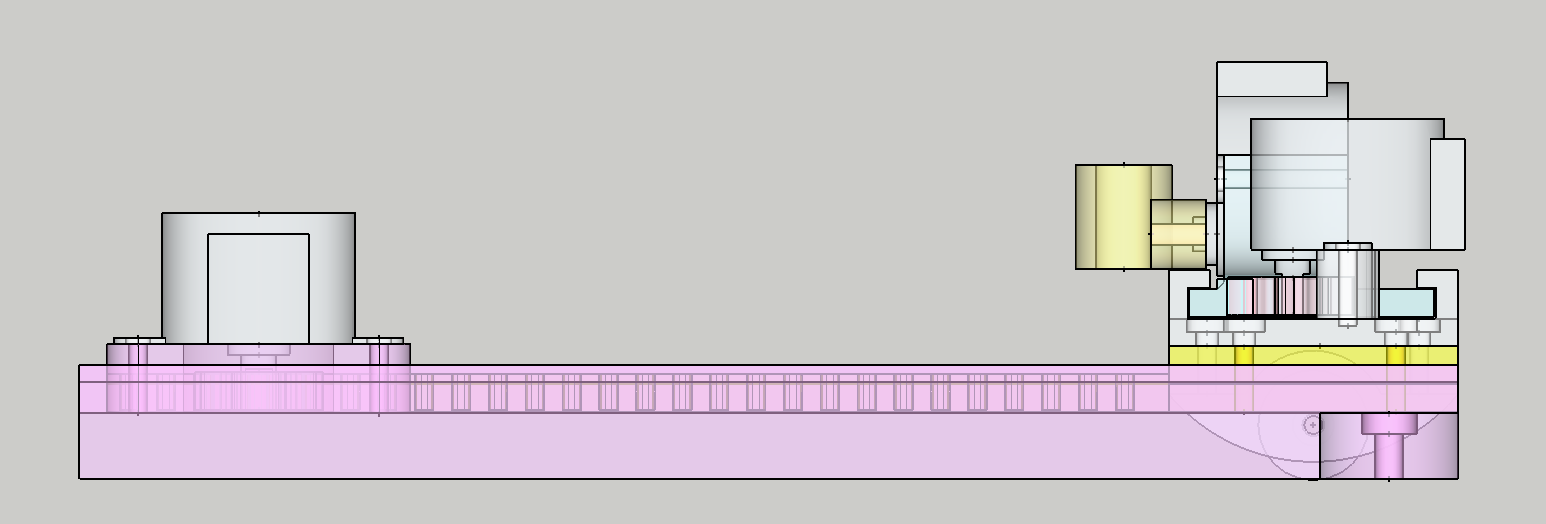
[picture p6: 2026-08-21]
reference/week4/Arduino mini CNC plotter - 4607077/images/Screen_Shot_2020-09-26_at_20.14.03.png

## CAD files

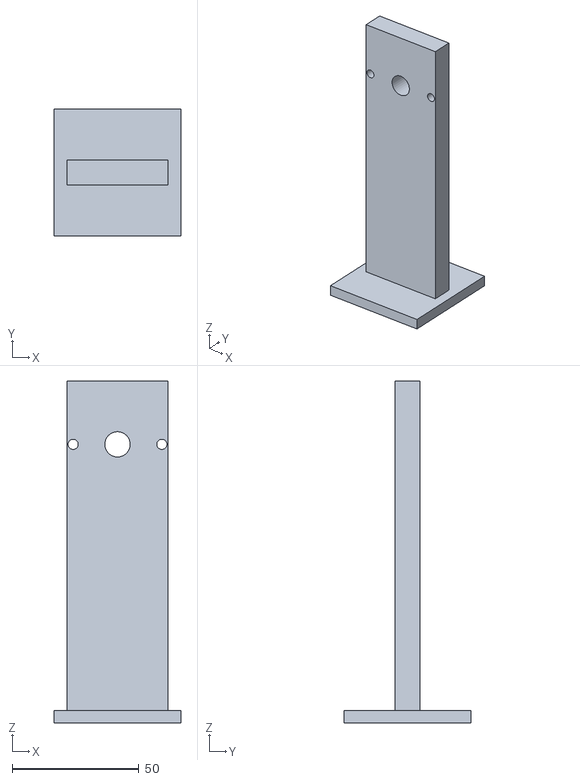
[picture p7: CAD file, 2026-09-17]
cad/medicinewheelstand.stl
50.0 x 50.0 x 135.0

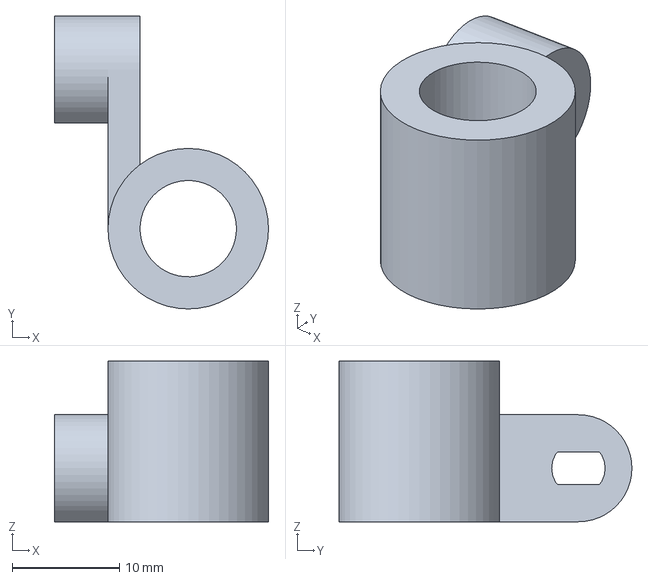
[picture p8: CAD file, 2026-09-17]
reference/week4/Arduino mini CNC plotter - 4607077/files/Unnamed7.FCStd
20.0 x 27.4 x 15.0 mm

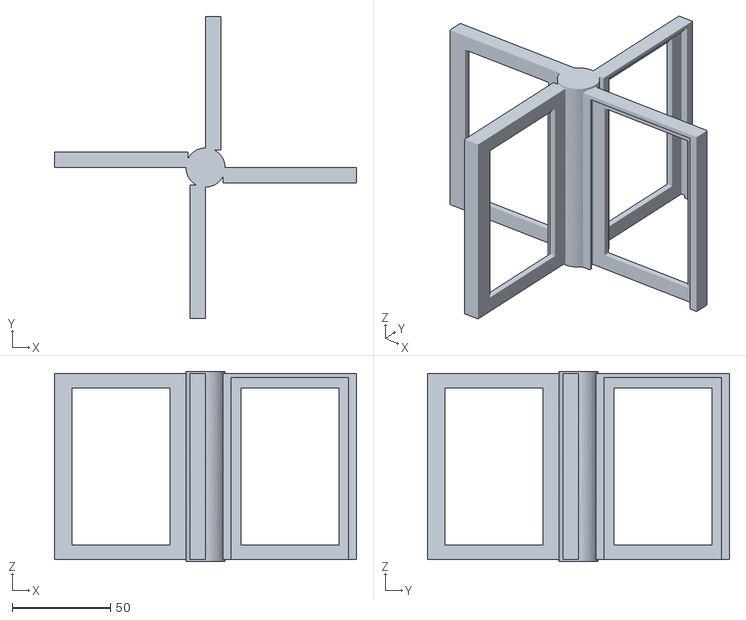
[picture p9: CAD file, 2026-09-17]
cad/new3d.stl
154.0 x 154.0 x 97.0

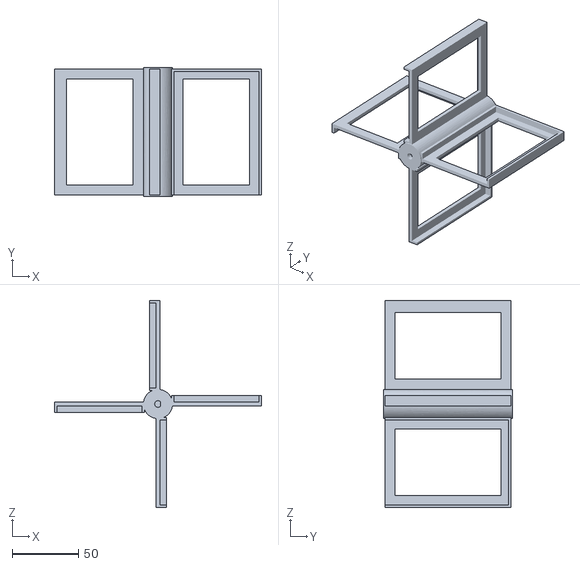
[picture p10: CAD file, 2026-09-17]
cad/new3d1.stl
156.0 x 97.0 x 156.0

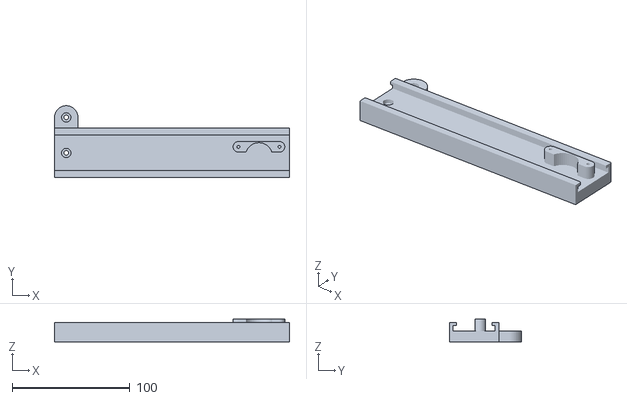
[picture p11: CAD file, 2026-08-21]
cad/B.stl
200.0 x 61.0 x 19.5

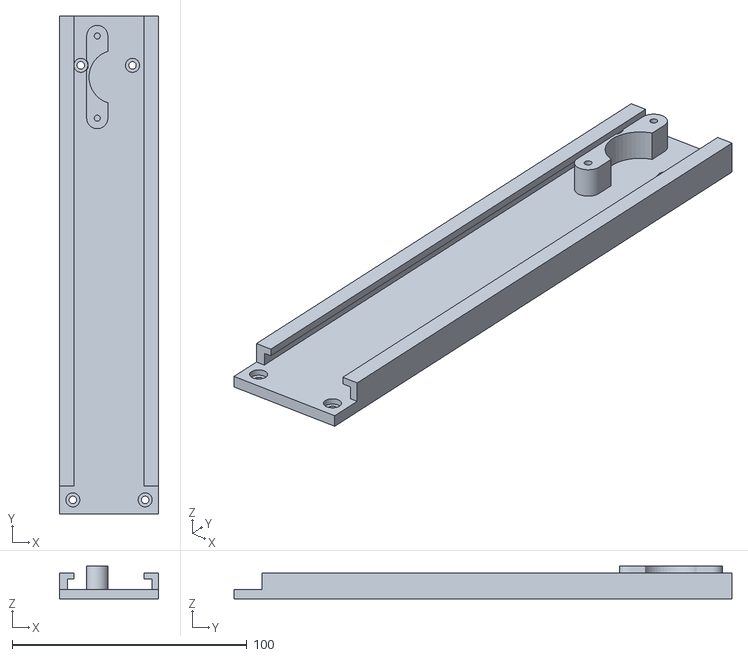
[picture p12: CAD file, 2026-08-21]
cad/1.stl
42.0 x 212.0 x 14.0

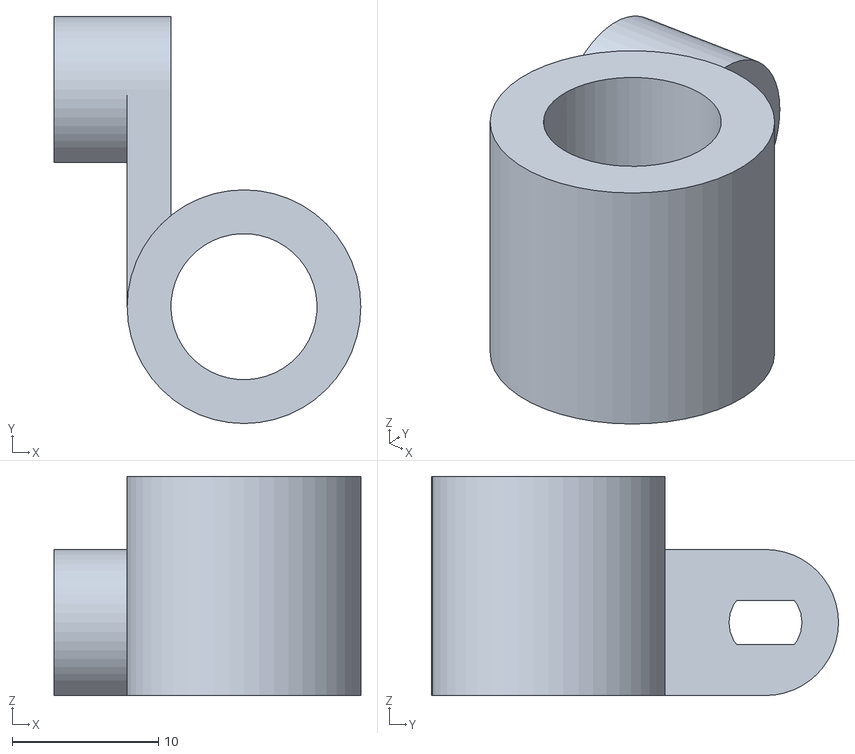
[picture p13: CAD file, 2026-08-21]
cad/A.stl
21.0 x 27.9 x 15.0

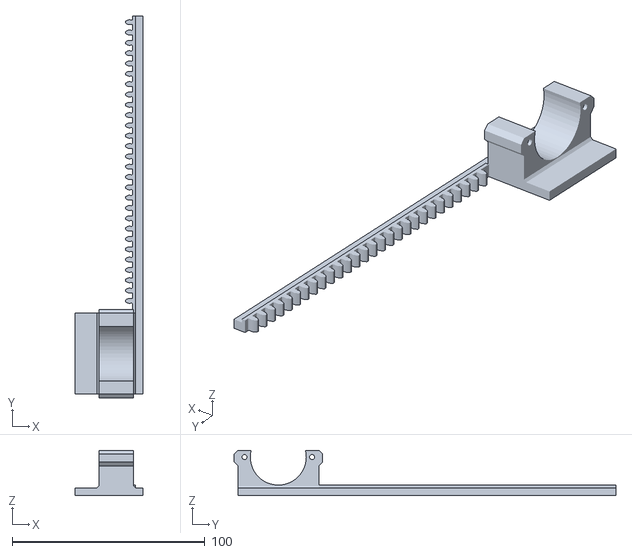
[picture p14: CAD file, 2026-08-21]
cad/Arduino_mini_CNC_plotter-N1.stl
35.5 x 198.0 x 23.5

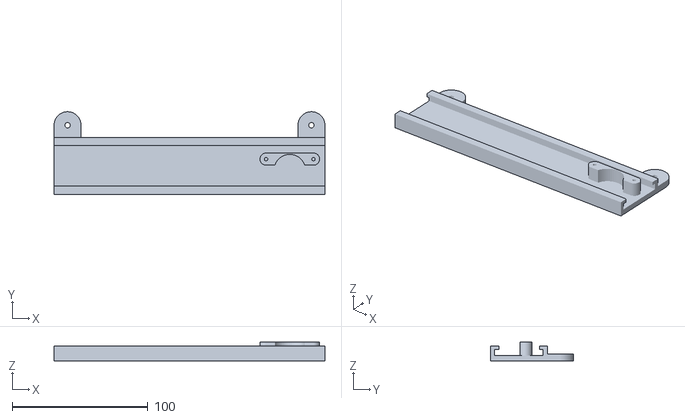
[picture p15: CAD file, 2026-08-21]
cad/4.stl
200.0 x 61.0 x 14.0

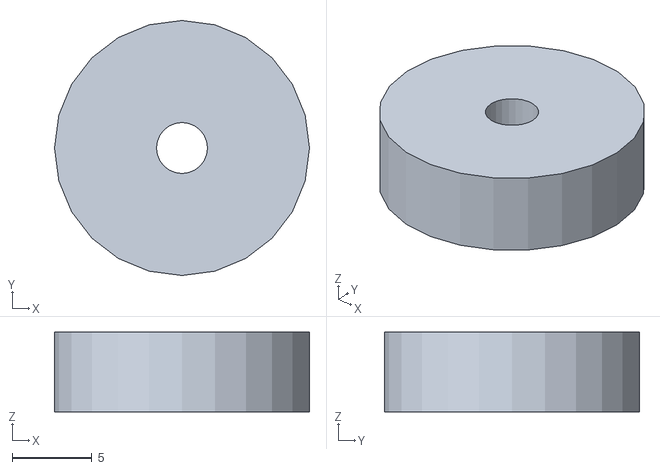
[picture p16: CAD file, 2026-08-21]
cad/7.stl
16.0 x 16.0 x 5.00

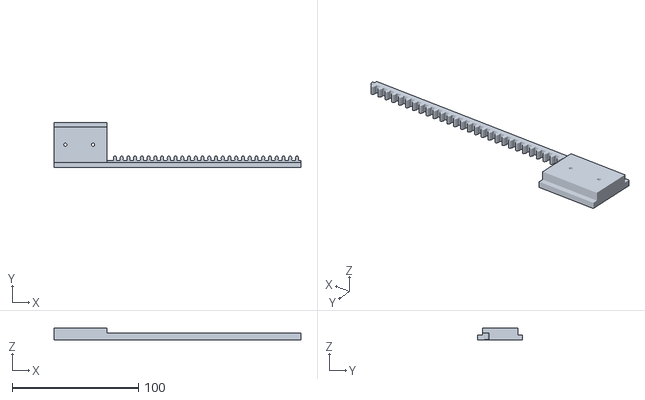
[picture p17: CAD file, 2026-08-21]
cad/3.stl
196.0 x 35.5 x 9.50

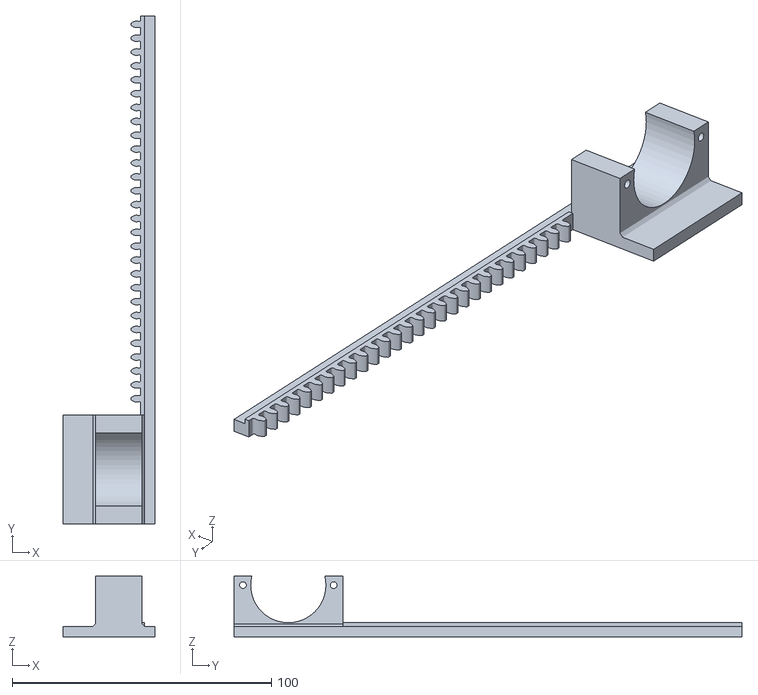
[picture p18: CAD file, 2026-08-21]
cad/2.stl
35.5 x 196.0 x 23.5

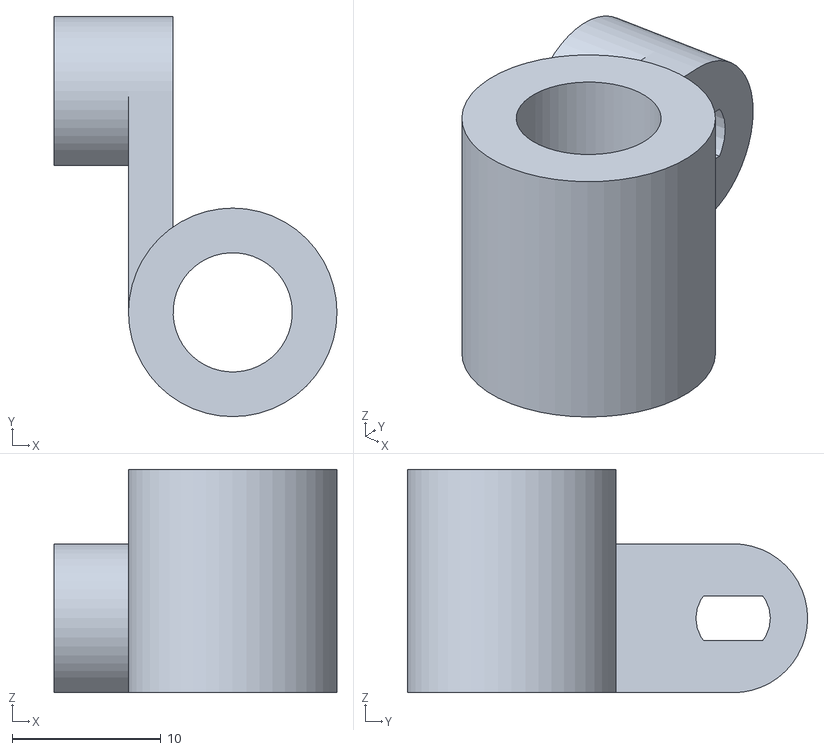
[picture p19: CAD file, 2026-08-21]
cad/8.stl
19.0 x 26.9 x 15.0

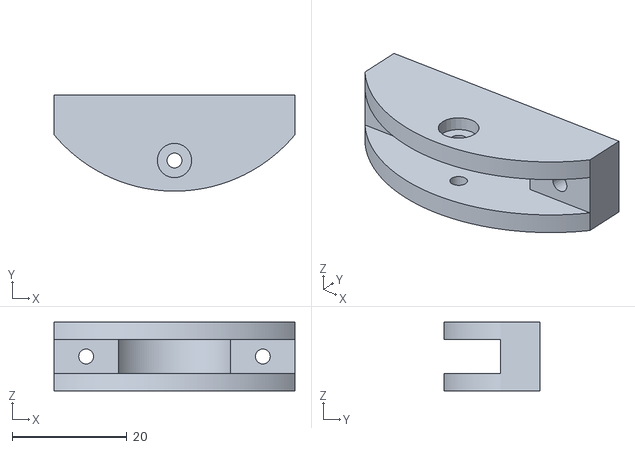
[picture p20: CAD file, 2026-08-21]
cad/6.stl
42.0 x 16.8 x 12.0

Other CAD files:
cad/blissupport.stl
cad/9.stl
cad/5.stl

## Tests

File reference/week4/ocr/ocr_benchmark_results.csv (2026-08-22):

Image | Engine | Extracted_Text | Detected_Dosage | Detected_EXP | Latency_ms | RAM_Delta_MB
images.jpeg | Tesseract | Tesseract error: tesseract is not installed or it's not in your PATH. See README file for more information. | None | None | 18.54 | 2.25
images.jpeg | RapidOCR | wtnstomachUlcensBreasteedngmiteen | DO NOTUSEPANADOL | -Ituuing othermedicirescortaehing paracetamot | ityouarallerpetoparscatamol | -ForchiiCrenbeloaage7 | Formorethan4ghouns for.Chtidrenaged 7-17excect | cnoeplonmedicaladnce | -Formorethanafewdays.atatime inadultsexcept | onmedicaiadvict | -ifaoyatthesealson thispackagingarebroken | on medicalsovce | tthePackaceuse-bydatebelowhesexgited | CHECKWITHTOURDOCTORBEFOREUSEIFYOU | -Aretasing warfarm (amedicireused to thin theblood) | HaveIiveroriodneyproblems | HOWTOUSEPANADOL | Tabiets | Age | How cften | 12-Adult1-2 | eery6nswthwaeasreoured | (maxmum8Teablets in24hrs) | 7-12 | eery-6hirswehwatasrecured | (maxmum4Tabietsin24hs) | Store below 30C. | STOPUSEAND TELLYOURDOCTORIFYOU | Haveanalergcsunreaction,shortnessofbreathor | wheezingattertakingPanadol | EACHTABLETCONTANS | -500mgParacetamol | -Potassium sorbate | -Nogluten,lactoseor sugar | aspreservatve | KEEPTOTHERECOMMENDEDDOSAGE | Han ventoseistaken orsusectednngthePosons | 4g, 500mg | None | 2768.0 | 18.56
images.jpeg | EasyOCR | tld | 5e | 7an | 7ia | Eeea | Gn#abms inad4#$ erept | Kareo en | 32 | CHETILTOUDOLIO EOQUSDDU | Tuto | Htadto ththbor | DOHOUSE BALADOI | Foactd | Rac6rrnn | 12-4u | (mwtun 8 | 7-12 | Z53 | Esbzsi | Ston EtloUIC | EUHDLUDILCHETL | geruss 0 rreamer | Petadol | @cABIEcoxiaS | 50876 | Acleisi sotate | E3ec 874 | Dezenelie | CEOHERECDI | TENDEQ DoSnGE | Renole | ie * | tannel | None | None | 2375.19 | 70.5
images.jpeg | DocTR | Reduces fever | Suitable tor: | . Pecolywithistomach ulcers . Breasteeding mithers | DONOT USEPANADOL | it you are allergicto paracatamor | uuns other medicines containing paracatamot | -For chieren below a89 escepton medicaladice | . For more than48hours for.children aged 1-17 except | on medicaladvice | For more thanaler daysatatime inadultsecept | on medical acvice | 22y of the seals onthis packagngare broken | . t the package use-by date below hes expired | CHECK WITHYOUR DOCTOR BEFORE - USE IF YOU | Have liveror kidney problems | Are taing wartarn(amedicine used to thin the blood) | HOW TO USE PANADOL | Age | Tablets | How otten | eery4-6trswthwcber as regured | 12-Adult | 1-2 | (maxmum 8Tablets in 24 hrs) | - | every4-6hrsath wateras requred | 7-12 | W-1 | max mum 4 Tabletsin24 hes) | Store below 30C. | STOPL USE ANDI TELLYOUR,DOCTOR IEYOU | Have an allergicskin reaction, shortnessof breath or | wheezing after taking Panadol. | EACHTABLETCONTAINS | 500mg Paracetamol | Potassium sorbate | . No guten, lactoseorsugar | as preservative | KEEPTO THE RECOMMENDED DOSAGE | an overdose is takenor suspected, ring. the Poisons | n Ran0.764760 | 500mg | None | 1743.23 | 354.1
images.jpeg | DocTR-Heavy | Reduces Nver | Suitable lor: | Paople - h somach ulcers - Breasteeding mithers | DONDTUSEENNADOL | it you are allergicto paracatamol | - = uons! other medi cines containing paracetamol | -For chicren below ago escepton med at adice | - For more than 48hours for children - | aged 7-17 excect | on medical advice | -For more than aler days ata time inadults except | on med cal advice | a 22y: of the seals ont this packagingare broken | i the package use-by date below hes expired | CHECKI WITH TOURDOCTORELOREUSD IP YOUR | Hae liver or lidney problems | Aretaung warfann (amedicine used to thin the blood) | HOWTOUSE PANADOL | Age - | Tabl ets | How otten | eery4-6irswthy water as requ o | 12-Adult 1-2 | (maxmum: 8 Tablets in241 hrs) | eery - a wth water as required | 7-12 | A | max mum 4 Tabletsin 24 has) | Store below 30C. | STOPUSE ENOTRESQUIDGSIRIENOU | Have an allergic: skin reaction. shortness of breath or | wheezingatter taking Panadol. | EACHIABLETCONTAINS | 500mg Paracetamol | Potassium sorbate | No: gluten, lactose orsugar | as preservative | REPIOTRERCOMMENOED DOSAGE | ring the Poisons | anoverdose is taken or suspected, Kon0.764 766) | 500mg | None | 2116.3 | 0.0
images.jpeg | SuryaOCR | SuryaOCR not installed | None | None | 0.0 | 0.0
images.jpeg | PaddleOCR | PaddleOCR not installed | None | None | 0.0 | 0.0
images.jpeg | PaddleOCR-VL | PaddleOCR-VL error: Image features and image tokens do not match: tokens: 0, features 196 | None | None | 1832.55 | 7.0
sample_blister_1.jpg | Tesseract | Tesseract error: tesseract is not installed or it's not in your PATH. See README file for more information. | None | None | 17.53 | 0.88
sample_blister_1.jpg | RapidOCR | PARACETAMOL 50Omg | EXP11/2026 | None | 11/2026 | 1090.93 | 4.45
sample_blister_1.jpg | EasyOCR | PARACETAMOL 500mg | EXP 11/2026 | 500mg | 11/2026 | 686.91 | 20.71
sample_blister_1.jpg | DocTR | PARACETAMOL 500mg | EXP 11/2026 | 500mg | 11/2026 | 578.46 | 187.71
sample_blister_1.jpg | DocTR-Heavy | PARACETAMOL 500mg | EXP 11/2026 | 500mg | 11/2026 | 978.34 | 206.11
sample_blister_1.jpg | SuryaOCR | SuryaOCR not installed | None | None | 0.0 | 0.0
sample_blister_1.jpg | PaddleOCR | PaddleOCR not installed | None | None | 0.0 | 0.0
sample_blister_1.jpg | PaddleOCR-VL | PaddleOCR-VL error: Image features and image tokens do not match: tokens: 0, features 294 | None | None | 2596.07 | 0.0
sample_blister_2.jpg | Tesseract | Tesseract error: tesseract is not installed or it's not in your PATH. See README file for more information. | None | None | 19.61 | 0.01
sample_blister_2.jpg | RapidOCR | IBUPROFEN 200 mg | EXP:05/2025 | 200 mg | 05/2025 | 832.65 | 0.0
sample_blister_2.jpg | EasyOCR | IBUPROFEN 200 mg | EXP: 05/2025 | 200 mg | 05/2025 | 858.83 | 92.85
sample_blister_2.jpg | DocTR | BUPROFEN 200 mg | EXP:05/2025 | 200 mg | 05/2025 | 570.04 | 184.48
sample_blister_2.jpg | DocTR-Heavy | IBUPROFEN 200 mg | EXP: 05/2025 | 200 mg | 05/2025 | 1015.67 | 154.09
sample_blister_2.jpg | SuryaOCR | SuryaOCR not installed | None | None | 0.0 | 0.0
sample_blister_2.jpg | PaddleOCR | PaddleOCR not installed | None | None | 0.0 | 0.0
sample_blister_2.jpg | PaddleOCR-VL | PaddleOCR-VL error: Image features and image tokens do not match: tokens: 0, features 294 | None | None | 2593.1 | 0.0
sample_blister_3.jpg | Tesseract | Tesseract error: tesseract is not installed or it's not in your PATH. See README file for more information. | None | None | 8.57 | 0.0
sample_blister_3.jpg | RapidOCR | AM0XICILLIN 250mg | expiry 12-2024 | 250mg | 12-2024 | 456.29 | 0.51
sample_blister_3.jpg | EasyOCR | AMOXICILLIN 250mg | expiry 12-2024 | 250mg | 12-2024 | 1085.54 | 98.41
sample_blister_3.jpg | DocTR | AMOXICILLIN 250mg | expiry 12-2024 | 250mg | 12-2024 | 573.91 | 177.42
sample_blister_3.jpg | DocTR-Heavy | AMOXICILLIN 250mg | expiry 12-2024 | 250mg | 12-2024 | 966.85 | 220.35
sample_blister_3.jpg | SuryaOCR | SuryaOCR not installed | None | None | 0.0 | 0.0
sample_blister_3.jpg | PaddleOCR | PaddleOCR not installed | None | None | 0.0 | 0.0
sample_blister_3.jpg | PaddleOCR-VL | PaddleOCR-VL error: Image features and image tokens do not match: tokens: 0, features 294 | None | None | 2598.44 | 0.0

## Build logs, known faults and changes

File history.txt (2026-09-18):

commit system arch doc (2026-09-17)

A	docs/SYSTEM+ARCHITECTURE.md
commit moved around some files (2026-09-17)

D	app_lab_terminal/app_lab_terminal.ino
D	app_lab_terminal/attendance.db
D	app_lab_terminal/install_libs.py
D	app_lab_terminal/lcd_server.py
D	app_lab_terminal/main.py
R100	3dfinal/._meta	cad/._meta
R100	3dfinal/.gitignore	cad/.gitignore
R100	3dfinal/NOTES.md	cad/NOTES.md
R100	3dfinal/blissupport.stl	cad/blissupport.stl
R100	3dfinal/main.kcl	cad/main.kcl
R100	3dfinal/medicinewheelstand.stl	cad/medicinewheelstand.stl
R100	3dfinal/new3d.stl	cad/new3d.stl
R100	3dfinal/new3d1.stl	cad/new3d1.stl
R100	3dfinal/project.toml	cad/project.toml
M	scripts/adb_deploy.sh
commit Merge branch 'main' of github.com:RealASHWIN122/Blister-bot-main- (2026-09-17)
commit clean up repo phase 1 (2026-09-17)

D	WEEKLY CHECKINS/checkins/week1 summary
D	WEEKLY CHECKINS/checkins/week1_documentation.md
D	Week 1/blister_bot.blend
D	Week 1/blister_bot.blend1
D	Week 1/create_blister_bot_model.py
D	Week 1/frames/frame_000.jpg
D	Week 1/frames/frame_001.jpg
D	Week 1/frames/frame_002.jpg
D	Week 1/frames/frame_003.jpg
D	Week 1/frames/frame_004.jpg
D	Week 1/frames/frame_005.jpg
D	Week 1/frames/frame_006.jpg
D	Week 1/frames/frame_007.jpg
D	Week 1/frames/frame_008.jpg
D	Week 1/frames/frame_009.jpg
D	Week 1/generate_pdf_report.py
D	Week 1/renders/render_front.png
D	Week 1/renders/render_mechanism.png
D	Week 1/renders/render_perspective.png
D	Week 1/scoring mechanism/3d_cutting_animation.html
D	Week 1/scoring mechanism/Scoring_Mechanism_Report.pdf
D	Week 1/scoring mechanism/anim_frames/frame_0001.png
D	Week 1/scoring mechanism/anim_frames/frame_0002.png
D	Week 1/scoring mechanism/anim_frames/frame_0003.png
D	Week 1/scoring mechanism/anim_frames/frame_0004.png
D	Week 1/scoring mechanism/anim_frames/frame_0005.png
D	Week 1/scoring mechanism/anim_frames/frame_0006.png
D	Week 1/scoring mechanism/anim_frames/frame_0007.png
D	Week 1/scoring mechanism/anim_frames/frame_0008.png
D	Week 1/scoring mechanism/anim_frames/frame_0009.png
D	Week 1/scoring mechanism/anim_frames/frame_0010.png
D	Week 1/scoring mechanism/anim_frames/frame_0011.png
D	Week 1/scoring mechanism/anim_frames/frame_0012.png
D	Week 1/scoring mechanism/anim_frames/frame_0013.png
D	Week 1/scoring mechanism/anim_frames/frame_0014.png
D	Week 1/scoring mechanism/anim_frames/frame_0015.png
D	Week 1/scoring mechanism/anim_frames/frame_0016.png
D	Week 1/scoring mechanism/anim_frames/frame_0017.png
D	Week 1/scoring mechanism/anim_frames/frame_0018.png
D	Week 1/scoring mechanism/anim_frames/frame_0019.png
D	Week 1/scoring mechanism/anim_frames/frame_0020.png
D	Week 1/scoring mechanism/anim_frames/frame_0021.png
D	Week 1/scoring mechanism/anim_frames/frame_0022.png
D	Week 1/scoring mechanism/anim_frames/frame_0023.png
D	Week 1/scoring mechanism/anim_frames/frame_0024.png
D	Week 1/scoring mechanism/anim_frames/frame_0025.png
D	Week 1/scoring mechanism/anim_frames/frame_0026.png
D	Week 1/scoring mechanism/anim_frames/frame_0027.png
D	Week 1/scoring mechanism/anim_frames/frame_0028.png
D	Week 1/scoring mechanism/anim_frames/frame_0029.png
D	Week 1/scoring mechanism/anim_frames/frame_0030.png
D	Week 1/scoring mechanism/anim_frames/frame_0031.png
D	Week 1/scoring mechanism/anim_frames/frame_0032.png
D	Week 1/scoring mechanism/anim_frames/frame_0033.png
D	Week 1/scoring mechanism/anim_frames/frame_0034.png
D	Week 1/scoring mechanism/anim_frames/frame_0035.png
D	Week 1/scoring mechanism/anim_frames/frame_0036.png
D	Week 1/scoring mechanism/anim_frames/frame_0037.png
D	Week 1/scoring mechanism/anim_frames/frame_0038.png
D	Week 1/scoring mechanism/anim_frames/frame_0039.png
D	Week 1/scoring mechanism/anim_frames/frame_0040.png
D	Week 1/scoring mechanism/anim_frames/frame_0041.png
D	Week 1/scoring mechanism/anim_frames/frame_0042.png
D	Week 1/scoring mechanism/anim_frames/frame_0043.png
D	Week 1/scoring mechanism/anim_frames/frame_0044.png
D	Week 1/scoring mechanism/anim_frames/frame_0045.png
D	Week 1/scoring mechanism/anim_frames/frame_0046.png
D	Week 1/scoring mechanism/anim_frames/frame_0047.png
D	Week 1/scoring mechanism/anim_frames/frame_0048.png
D	Week 1/scoring mechanism/anim_frames/frame_0049.png
D	Week 1/scoring mechanism/anim_frames/frame_0050.png
D	Week 1/scoring mechanism/anim_frames/frame_0051.png
D	Week 1/scoring mechanism/anim_frames/frame_0052.png
D	Week 1/scoring mechanism/anim_frames/frame_0053.png
D	Week 1/scoring mechanism/anim_frames/frame_0054.png
D	Week 1/scoring mechanism/anim_frames/frame_0055.png
D	Week 1/scoring mechanism/anim_frames/frame_0056.png
D	Week 1/scoring mechanism/anim_frames/frame_0057.png
D	Week 1/scoring mechanism/anim_frames/frame_0058.png
D	Week 1/scoring mechanism/anim_frames/frame_0059.png
D	Week 1/scoring mechanism/anim_frames/frame_0060.png
D	Week 1/scoring mechanism/anim_frames/frame_0061.png
D	Week 1/scoring mechanism/anim_frames/frame_0062.png
D	Week 1/scoring mechanism/anim_frames/frame_0063.png
D	Week 1/scoring mechanism/anim_frames/frame_0064.png
D	Week 1/scoring mechanism/anim_frames/frame_0065.png
D	Week 1/scoring mechanism/anim_frames/frame_0066.png
D	Week 1/scoring mechanism/anim_frames/frame_0067.png
D	Week 1/scoring mechanism/anim_frames/frame_0068.png
D	Week 1/scoring mechanism/anim_frames/frame_0069.png
D	Week 1/scoring mechanism/anim_frames/frame_0070.png
D	Week 1/scoring mechanism/anim_frames/frame_0071.png
D	Week 1/scoring mechanism/anim_frames/frame_0072.png
D	Week 1/scoring mechanism/anim_frames/frame_0073.png
D	Week 1/scoring mechanism/anim_frames/frame_0074.png
D	Week 1/scoring mechanism/anim_frames/frame_0075.png
D	Week 1/scoring mechanism/anim_frames/frame_0076.png
D	Week 1/scoring mechanism/anim_frames/frame_0077.png
D	Week 1/scoring mechanism/anim_frames/frame_0078.png
D	Week 1/scoring mechanism/anim_frames/frame_0079.png
D	Week 1/scoring mechanism/anim_frames/frame_0080.png
D	Week 1/scoring mechanism/anim_frames/frame_0081.png
D	Week 1/scoring mechanism/anim_frames/frame_0082.png
D	Week 1/scoring mechanism/anim_frames/frame_0083.png
D	Week 1/scoring mechanism/anim_frames/frame_0084.png
D	Week 1/scoring mechanism/anim_frames/frame_0085.png
D	Week 1/scoring mechanism/anim_frames/frame_0086.png
D	Week 1/scoring mechanism/anim_frames/frame_0087.png
D	Week 1/scoring mechanism/anim_frames/frame_0088.png
D	Week 1/scoring mechanism/anim_frames/frame_0089.png
D	Week 1/scoring mechanism/anim_frames/frame_0090.png
D	Week 1/scoring mechanism/anim_frames/frame_0091.png
D	Week 1/scoring mechanism/anim_frames/frame_0092.png
D	Week 1/scoring mechanism/anim_frames/frame_0093.png
D	Week 1/scoring mechanism/anim_frames/frame_0094.png
D	Week 1/scoring mechanism/anim_frames/frame_0095.png
D	Week 1/scoring mechanism/anim_frames/frame_0096.png
D	Week 1/scoring mechanism/anim_frames/frame_0097.png
D	Week 1/scoring mechanism/anim_frames/frame_0098.png
D	Week 1/scoring mechanism/anim_frames/frame_0099.png
D	Week 1/scoring mechanism/anim_frames/frame_0100.png
D	Week 1/scoring mechanism/anim_frames/frame_0101.png
D	Week 1/scoring mechanism/anim_frames/frame_0102.png
D	Week 1/scoring mechanism/anim_frames/frame_0103.png
D	Week 1/scoring mechanism/anim_frames/frame_0104.png
D	Week 1/scoring mechanism/anim_frames/frame_0105.png
D	Week 1/scoring mechanism/anim_frames/frame_0106.png
D	Week 1/scoring mechanism/anim_frames/frame_0107.png
D	Week 1/scoring mechanism/anim_frames/frame_0108.png
D	Week 1/scoring mechanism/anim_frames/frame_0109.png
D	Week 1/scoring mechanism/anim_frames/frame_0110.png
D	Week 1/scoring mechanism/anim_frames/frame_0111.png
D	Week 1/scoring mechanism/anim_frames/frame_0112.png
D	Week 1/scoring mechanism/anim_frames/frame_0113.png
D	Week 1/scoring mechanism/anim_frames/frame_0114.png
D	Week 1/scoring mechanism/anim_frames/frame_0115.png
D	Week 1/scoring mechanism/anim_frames/frame_0116.png
D	Week 1/scoring mechanism/anim_frames/frame_0117.png
D	Week 1/scoring mechanism/anim_frames/frame_0118.png
D	Week 1/scoring mechanism/anim_frames/frame_0119.png
D	Week 1/scoring mechanism/anim_frames/frame_0120.png
D	Week 1/scoring mechanism/animate_scoring_mechanism.py
D	Week 1/scoring mechanism/compile_scoring_video.py
D	Week 1/scoring mechanism/encode_mp4.py
D	Week 1/scoring mechanism/generate_scoring_pdf.py
D	Week 1/scoring mechanism/scoring_gantry_controller.ino
D	Week 1/scoring mechanism/scoring_mechanism.blend
D	Week 1/scoring mechanism/scoring_mechanism_demo.mp4
D	Week 1/scoring mechanism/scoring_toolhead.png
D	Week 1/scoring mechanism/tablet_ejection.png
D	Week 1/scoring mechanism/u_flap_scored.png
D	Week 1/vertical scoring mechanism/Vertical_Scoring_Report.pdf
D	Week 1/vertical scoring mechanism/animate_vertical_scoring.py
D	Week 1/vertical scoring mechanism/encode_vertical_mp4.py
D	Week 1/vertical scoring mechanism/generate_vertical_pdf.py
D	Week 1/vertical scoring mechanism/vert_frames/frame_0001.png
D	Week 1/vertical scoring mechanism/vert_frames/frame_0002.png
D	Week 1/vertical scoring mechanism/vert_frames/frame_0003.png
D	Week 1/vertical scoring mechanism/vert_frames/frame_0004.png
D	Week 1/vertical scoring mechanism/vert_frames/frame_0005.png
D	Week 1/vertical scoring mechanism/vert_frames/frame_0006.png
D	Week 1/vertical scoring mechanism/vert_frames/frame_0007.png
D	Week 1/vertical scoring mechanism/vert_frames/frame_0008.png
D	Week 1/vertical scoring mechanism/vert_frames/frame_0009.png
D	Week 1/vertical scoring mechanism/vert_frames/frame_0010.png
D	Week 1/vertical scoring mechanism/vert_frames/frame_0011.png
D	Week 1/vertical scoring mechanism/vert_frames/frame_0012.png
D	Week 1/vertical scoring mechanism/vert_frames/frame_0013.png
D	Week 1/vertical scoring mechanism/vert_frames/frame_0014.png
D	Week 1/vertical scoring mechanism/vert_frames/frame_0015.png
D	Week 1/vertical scoring mechanism/vert_frames/frame_0016.png
D	Week 1/vertical scoring mechanism/vert_frames/frame_0017.png
D	Week 1/vertical scoring mechanism/vert_frames/frame_0018.png
D	Week 1/vertical scoring mechanism/vert_frames/frame_0019.png
D	Week 1/vertical scoring mechanism/vert_frames/frame_0020.png
D	Week 1/vertical scoring mechanism/vert_frames/frame_0021.png
D	Week 1/vertical scoring mechanism/vert_frames/frame_0022.png
D	Week 1/vertical scoring mechanism/vert_frames/frame_0023.png
D	Week 1/vertical scoring mechanism/vert_frames/frame_0024.png
D	Week 1/vertical scoring mechanism/vert_frames/frame_0025.png
D	Week 1/vertical scoring mechanism/vert_frames/frame_0026.png
D	Week 1/vertical scoring mechanism/vert_frames/frame_0027.png
D	Week 1/vertical scoring mechanism/vert_frames/frame_0028.png
D	Week 1/vertical scoring mechanism/vert_frames/frame_0029.png
D	Week 1/vertical scoring mechanism/vert_frames/frame_0030.png
D	Week 1/vertical scoring mechanism/vert_frames/frame_0031.png
D	Week 1/vertical scoring mechanism/vert_frames/frame_0032.png
D	Week 1/vertical scoring mechanism/vert_frames/frame_0033.png
D	Week 1/vertical scoring mechanism/vert_frames/frame_0034.png
D	Week 1/vertical scoring mechanism/vert_frames/frame_0035.png
D	Week 1/vertical scoring mechanism/vert_frames/frame_0036.png
D	Week 1/vertical scoring mechanism/vert_frames/frame_0037.png
D	Week 1/vertical scoring mechanism/vert_frames/frame_0038.png
D	Week 1/vertical scoring mechanism/vert_frames/frame_0039.png
D	Week 1/vertical scoring mechanism/vert_frames/frame_0040.png
D	Week 1/vertical scoring mechanism/vert_frames/frame_0041.png
D	Week 1/vertical scoring mechanism/vert_frames/frame_0042.png
D	Week 1/vertical scoring mechanism/vert_frames/frame_0043.png
D	Week 1/vertical scoring mechanism/vert_frames/frame_0044.png
D	Week 1/vertical scoring mechanism/vert_frames/frame_0045.png
D	Week 1/vertical scoring mechanism/vert_frames/frame_0046.png
D	Week 1/vertical scoring mechanism/vert_frames/frame_0047.png
D	Week 1/vertical scoring mechanism/vert_frames/frame_0048.png
D	Week 1/vertical scoring mechanism/vert_frames/frame_0049.png
D	Week 1/vertical scoring mechanism/vert_frames/frame_0050.png
D	Week 1/vertical scoring mechanism/vert_frames/frame_0051.png
D	Week 1/vertical scoring mechanism/vert_frames/frame_0052.png
D	Week 1/vertical scoring mechanism/vert_frames/frame_0053.png
D	Week 1/vertical scoring mechanism/vert_frames/frame_0054.png
D	Week 1/vertical scoring mechanism/vert_frames/frame_0055.png
D	Week 1/vertical scoring mechanism/vert_frames/frame_0056.png
D	Week 1/vertical scoring mechanism/vert_frames/frame_0057.png
D	Week 1/vertical scoring mechanism/vert_frames/frame_0058.png
D	Week 1/vertical scoring mechanism/vert_frames/frame_0059.png
D	Week 1/vertical scoring mechanism/vert_frames/frame_0060.png
D	Week 1/vertical scoring mechanism/vert_frames/frame_0061.png
D	Week 1/vertical scoring mechanism/vert_frames/frame_0062.png
D	Week 1/vertical scoring mechanism/vert_frames/frame_0063.png
D	Week 1/vertical scoring mechanism/vert_frames/frame_0064.png
D	Week 1/vertical scoring mechanism/vert_frames/frame_0065.png
D	Week 1/vertical scoring mechanism/vert_frames/frame_0066.png
D	Week 1/vertical scoring mechanism/vert_frames/frame_0067.png
D	Week 1/vertical scoring mechanism/vert_frames/frame_0068.png
D	Week 1/vertical scoring mechanism/vert_frames/frame_0069.png
D	Week 1/vertical scoring mechanism/vert_frames/frame_0070.png
D	Week 1/vertical scoring mechanism/vert_frames/frame_0071.png
D	Week 1/vertical scoring mechanism/vert_frames/frame_0072.png
D	Week 1/vertical scoring mechanism/vert_frames/frame_0073.png
D	Week 1/vertical scoring mechanism/vert_frames/frame_0074.png
D	Week 1/vertical scoring mechanism/vert_frames/frame_0075.png
D	Week 1/vertical scoring mechanism/vert_frames/frame_0076.png
D	Week 1/vertical scoring mechanism/vert_frames/frame_0077.png
D	Week 1/vertical scoring mechanism/vert_frames/frame_0078.png
D	Week 1/vertical scoring mechanism/vert_frames/frame_0079.png
D	Week 1/vertical scoring mechanism/vert_frames/frame_0080.png
D	Week 1/vertical scoring mechanism/vert_frames/frame_0081.png
D	Week 1/vertical scoring mechanism/vert_frames/frame_0082.png
D	Week 1/vertical scoring mechanism/vert_frames/frame_0083.png
D	Week 1/vertical scoring mechanism/vert_frames/frame_0084.png
D	Week 1/vertical scoring mechanism/vert_frames/frame_0085.png
D	Week 1/vertical scoring mechanism/vert_frames/frame_0086.png
D	Week 1/vertical scoring mechanism/vert_frames/frame_0087.png
D	Week 1/vertical scoring mechanism/vert_frames/frame_0088.png
D	Week 1/vertical scoring mechanism/vert_frames/frame_0089.png
D	Week 1/vertical scoring mechanism/vert_frames/frame_0090.png
D	Week 1/vertical scoring mechanism/vert_frames/frame_0091.png
D	Week 1/vertical scoring mechanism/vert_frames/frame_0092.png
D	Week 1/vertical scoring mechanism/vert_frames/frame_0093.png
D	Week 1/vertical scoring mechanism/vert_frames/frame_0094.png
D	Week 1/vertical scoring mechanism/vert_frames/frame_0095.png
D	Week 1/vertical scoring mechanism/vert_frames/frame_0096.png
D	Week 1/vertical scoring mechanism/vert_frames/frame_0097.png
D	Week 1/vertical scoring mechanism/vert_frames/frame_0098.png
D	Week 1/vertical scoring mechanism/vert_frames/frame_0099.png
D	Week 1/vertical scoring mechanism/vert_frames/frame_0100.png
D	Week 1/vertical scoring mechanism/vert_frames/frame_0101.png
D	Week 1/vertical scoring mechanism/vert_frames/frame_0102.png
D	Week 1/vertical scoring mechanism/vert_frames/frame_0103.png
D	Week 1/vertical scoring mechanism/vert_frames/frame_0104.png
D	Week 1/vertical scoring mechanism/vert_frames/frame_0105.png
D	Week 1/vertical scoring mechanism/vert_frames/frame_0106.png
D	Week 1/vertical scoring mechanism/vert_frames/frame_0107.png
D	Week 1/vertical scoring mechanism/vert_frames/frame_0108.png
D	Week 1/vertical scoring mechanism/vert_frames/frame_0109.png
D	Week 1/vertical scoring mechanism/vert_frames/frame_0110.png
D	Week 1/vertical scoring mechanism/vert_frames/frame_0111.png
D	Week 1/vertical scoring mechanism/vert_frames/frame_0112.png
D	Week 1/vertical scoring mechanism/vert_frames/frame_0113.png
D	Week 1/vertical scoring mechanism/vert_frames/frame_0114.png
D	Week 1/vertical scoring mechanism/vert_frames/frame_0115.png
D	Week 1/vertical scoring mechanism/vert_frames/frame_0116.png
D	Week 1/vertical scoring mechanism/vert_frames/frame_0117.png
D	Week 1/vertical scoring mechanism/vert_frames/frame_0118.png
D	Week 1/vertical scoring mechanism/vert_frames/frame_0119.png
D	Week 1/vertical scoring mechanism/vert_frames/frame_0120.png
D	Week 1/vertical scoring mechanism/vertical_plunger_eject.png
D	Week 1/vertical scoring mechanism/vertical_scoring_mechanism.blend
D	Week 1/vertical scoring mechanism/vertical_strip_ejection_demo.mp4
D	Week 1/vertical scoring mechanism/vertical_strip_plunger_animation.html
D	Week 1/vertical scoring mechanism/vertical_strip_toolhead.png
D	Week 1/vertical scoring mechanism/vertical_u_flap.png
R100	Week 1/Week1_Documentation.md	docs/Week1_Documentation.md
R100	WEEKLY CHECKINS/week1.md	docs/week1.md
R100	Week 1/Project Blueprint.pdf	reference/Project Blueprint.pdf
R100	Week 1/README.md	reference/README.md
R100	Week 1/blueprint_text.txt	reference/blueprint_text.txt
commit Combine week1 documentation and summaries into week1.md (2026-09-17)

D	WEEKLY CHECKINS/checkins/Week1_Documentation.pdf
A	WEEKLY CHECKINS/week1.md
M	stepper_motor_controller/app.py
M	stepper_motor_controller/cnc_plotter.ino
M	stepper_motor_controller/templates/index.html
A	week2/Arduino mini CNC plotter - 4607077/files/Unnamed7.FCStd
commit last support stand (2026-09-17)

A	3dfinal/blissupport.stl
commit added medicine wheel stand stl file (2026-09-16)

A	3dfinal/medicinewheelstand.stl
commit added another stl file (2026-09-13)

A	3dfinal/new3d1.stl
commit added stl file (2026-09-13)

A	3dfinal/new3d.stl
commit Added 3d  files (2026-09-13)

A	.vscode/settings.json
A	3dfinal/._meta
A	3dfinal/.gitignore
A	3dfinal/NOTES.md
A	3dfinal/main.kcl
A	3dfinal/project.toml
commit Update connections.md to explicitly mention 6V 4xAA battery pack (2026-09-12)

M	docs/connections.md
commit Update connections.md with breadboard and driver details (2026-09-12)

A	docs/connections.md
commit Organize repository structure and add stepper motor web controller (2026-09-12)

R100	sample_result.jpg	assets/sample_result.jpg
R100	temp_capture.jpg	assets/temp_capture.jpg
R100	arduinohackdraft1report.pdf	docs/arduinohackdraft1report.pdf
R100	blueprinthack1.txt	docs/blueprinthack1.txt
R100	main_edge_terminal.py	edge_terminal/main_edge_terminal.py
R100	requirements_edge_terminal.txt	edge_terminal/requirements_edge_terminal.txt
R100	adb_deploy.sh	scripts/adb_deploy.sh
R100	deploy_ai_terminal.sh	scripts/deploy_ai_terminal.sh
R100	deploy_appliance.sh	scripts/deploy_appliance.sh
R100	deploy_wireless_display.sh	scripts/deploy_wireless_display.sh
R100	setup_appliance.sh	scripts/setup_appliance.sh
R100	setup_wifi.py	scripts/setup_wifi.py
R052	app.py	stepper_motor_controller/app.py
R100	check_serial.py	stepper_motor_controller/check_serial.py
R100	cnc_plotter.ino	stepper_motor_controller/cnc_plotter.ino
R100	deploy_to_uno.py	stepper_motor_controller/deploy_to_uno.py
A	stepper_motor_controller/templates/index.html
commit Migrate deployment scripts, final apps, CNC code, and documentation to repository (2026-09-09)

A	adb_deploy.sh
A	app.py
A	app_lab_terminal/app_lab_terminal.ino
A	app_lab_terminal/attendance.db
A	app_lab_terminal/install_libs.py
A	app_lab_terminal/lcd_server.py
A	app_lab_terminal/main.py
A	arduinohackdraft1report.pdf
A	blueprinthack1.txt
A	check_serial.py
A	cnc_plotter.ino
A	deploy_ai_terminal.sh
A	deploy_appliance.sh
A	deploy_to_uno.py
A	deploy_wireless_display.sh
A	main_edge_terminal.py
A	requirements_edge_terminal.txt
A	setup_wifi.py
A	templates/index.html
commit Add appliance terminal and setup script with faster-whisper optimizations (2026-09-09)

A	appliance_terminal/README.md
A	appliance_terminal/__pycache__/appliance.cpython-313.pyc
A	appliance_terminal/appliance.py
A	setup_appliance.sh
commit feat: implement edge agent OCR and facial recognition tool integration with computer vision support (2026-09-09)

A	week2/edge_agent/__pycache__/edge_agent.cpython-313.pyc
M	week2/edge_agent/edge_agent.py
M	week2/facerecog-unoq/__pycache__/database.cpython-313.pyc
M	week2/ocr/__pycache__/benchmark_ocr.cpython-313.pyc
commit Update gitignore and add week2 action recognition scripts (2026-08-23)

M	.gitignore
A	week2/action-recog-applab/LICENSE
A	week2/action-recog-applab/README.md
A	week2/action-recog-applab/app.yaml
A	week2/action-recog-applab/assets/rubber-duckies-2.jpg
A	week2/action-recog-applab/assets/rubber-duckies-3.jpg
A	week2/action-recog-applab/assets/rubber-duckies-4.jpg
A	week2/action-recog-applab/assets/rubber-duckies-5.jpg
A	week2/action-recog-applab/assets/rubber-duckies-6.jpg
A	week2/action-recog-applab/assets/rubber-duckies-7.jpg
A	week2/action-recog-applab/assets/rubber-duckies-8.jpg
A	week2/action-recog-applab/assets/rubber-duckies-9.jpg
A	week2/action-recog-applab/assets/rubber-duckies.jpg
A	week2/action-recog-applab/cpp_server/Makefile
A	week2/action-recog-applab/cpp_server/edge-impulse-sdk/.gitignore
A	week2/action-recog-applab/cpp_server/edge-impulse-sdk/.mbedignore
A	week2/action-recog-applab/cpp_server/edge-impulse-sdk/CMSIS/Core/Include/cachel1_armv7.h
A	week2/action-recog-applab/cpp_server/edge-impulse-sdk/CMSIS/Core/Include/cmsis_armcc.h
A	week2/action-recog-applab/cpp_server/edge-impulse-sdk/CMSIS/Core/Include/cmsis_armclang.h
A	week2/action-recog-applab/cpp_server/edge-impulse-sdk/CMSIS/Core/Include/cmsis_armclang_ltm.h
A	week2/action-recog-applab/cpp_server/edge-impulse-sdk/CMSIS/Core/Include/cmsis_compiler.h
A	week2/action-recog-applab/cpp_server/edge-impulse-sdk/CMSIS/Core/Include/cmsis_gcc.h
A	week2/action-recog-applab/cpp_server/edge-impulse-sdk/CMSIS/Core/Include/cmsis_iccarm.h
A	week2/action-recog-applab/cpp_server/edge-impulse-sdk/CMSIS/Core/Include/cmsis_version.h
A	week2/action-recog-applab/cpp_server/edge-impulse-sdk/CMSIS/Core/Include/core_armv81mml.h
A	week2/action-recog-applab/cpp_server/edge-impulse-sdk/CMSIS/Core/Include/core_armv8mbl.h
A	week2/action-recog-applab/cpp_server/edge-impulse-sdk/CMSIS/Core/Include/core_armv8mml.h
A	week2/action-recog-applab/cpp_server/edge-impulse-sdk/CMSIS/Core/Include/core_cm0.h
A	week2/action-recog-applab/cpp_server/edge-impulse-sdk/CMSIS/Core/Include/core_cm0plus.h
A	week2/action-recog-applab/cpp_server/edge-impulse-sdk/CMSIS/Core/Include/core_cm1.h
A	week2/action-recog-applab/cpp_server/edge-impulse-sdk/CMSIS/Core/Include/core_cm23.h
A	week2/action-recog-applab/cpp_server/edge-impulse-sdk/CMSIS/Core/Include/core_cm3.h
A	week2/action-recog-applab/cpp_server/edge-impulse-sdk/CMSIS/Core/Include/core_cm33.h
A	week2/action-recog-applab/cpp_server/edge-impulse-sdk/CMSIS/Core/Include/core_cm35p.h
A	week2/action-recog-applab/cpp_server/edge-impulse-sdk/CMSIS/Core/Include/core_cm4.h
A	week2/action-recog-applab/cpp_server/edge-impulse-sdk/CMSIS/Core/Include/core_cm55.h
A	week2/action-recog-applab/cpp_server/edge-impulse-sdk/CMSIS/Core/Include/core_cm7.h
A	week2/action-recog-applab/cpp_server/edge-impulse-sdk/CMSIS/Core/Include/core_cm85.h
A	week2/action-recog-applab/cpp_server/edge-impulse-sdk/CMSIS/Core/Include/core_sc000.h
A	week2/action-recog-applab/cpp_server/edge-impulse-sdk/CMSIS/Core/Include/core_sc300.h
A	week2/action-recog-applab/cpp_server/edge-impulse-sdk/CMSIS/Core/Include/core_starmc1.h
A	week2/action-recog-applab/cpp_server/edge-impulse-sdk/CMSIS/Core/Include/mpu_armv7.h
A	week2/action-recog-applab/cpp_server/edge-impulse-sdk/CMSIS/Core/Include/mpu_armv8.h
A	week2/action-recog-applab/cpp_server/edge-impulse-sdk/CMSIS/Core/Include/pac_armv81.h
A	week2/action-recog-applab/cpp_server/edge-impulse-sdk/CMSIS/Core/Include/pmu_armv8.h
A	week2/action-recog-applab/cpp_server/edge-impulse-sdk/CMSIS/Core/Include/tz_context.h
A	week2/action-recog-applab/cpp_server/edge-impulse-sdk/CMSIS/DSP/Include/arm_common_tables.h
A	week2/action-recog-applab/cpp_server/edge-impulse-sdk/CMSIS/DSP/Include/arm_common_tables_f16.h
A	week2/action-recog-applab/cpp_server/edge-impulse-sdk/CMSIS/DSP/Include/arm_const_structs.h
A	week2/action-recog-applab/cpp_server/edge-impulse-sdk/CMSIS/DSP/Include/arm_const_structs_f16.h
A	week2/action-recog-applab/cpp_server/edge-impulse-sdk/CMSIS/DSP/Include/arm_helium_utils.h
A	week2/action-recog-applab/cpp_server/edge-impulse-sdk/CMSIS/DSP/Include/arm_math.h
A	week2/action-recog-applab/cpp_server/edge-impulse-sdk/CMSIS/DSP/Include/arm_math_f16.h
A	week2/action-recog-applab/cpp_server/edge-impulse-sdk/CMSIS/DSP/Include/arm_math_memory.h
A	week2/action-recog-applab/cpp_server/edge-impulse-sdk/CMSIS/DSP/Include/arm_math_types.h
A	week2/action-recog-applab/cpp_server/edge-impulse-sdk/CMSIS/DSP/Include/arm_math_types_f16.h
A	week2/action-recog-applab/cpp_server/edge-impulse-sdk/CMSIS/DSP/Include/arm_mve_tables.h
A	week2/action-recog-applab/cpp_server/edge-impulse-sdk/CMSIS/DSP/Include/arm_mve_tables_f16.h
A	week2/action-recog-applab/cpp_server/edge-impulse-sdk/CMSIS/DSP/Include/arm_sorting.h
A	week2/action-recog-applab/cpp_server/edge-impulse-sdk/CMSIS/DSP/Include/arm_vec_fft.h
A	week2/action-recog-applab/cpp_server/edge-impulse-sdk/CMSIS/DSP/Include/arm_vec_filtering.h
A	week2/action-recog-applab/cpp_server/edge-impulse-sdk/CMSIS/DSP/Include/arm_vec_math.h
A	week2/action-recog-applab/cpp_server/edge-impulse-sdk/CMSIS/DSP/Include/arm_vec_math_f16.h
A	week2/action-recog-applab/cpp_server/edge-impulse-sdk/CMSIS/DSP/Include/dsp/basic_math_functions.h
A	week2/action-recog-applab/cpp_server/edge-impulse-sdk/CMSIS/DSP/Include/dsp/basic_math_functions_f16.h
A	week2/action-recog-applab/cpp_server/edge-impulse-sdk/CMSIS/DSP/Include/dsp/bayes_functions.h
A	week2/action-recog-applab/cpp_server/edge-impulse-sdk/CMSIS/DSP/Include/dsp/bayes_functions_f16.h
A	week2/action-recog-applab/cpp_server/edge-impulse-sdk/CMSIS/DSP/Include/dsp/complex_math_functions.h
A	week2/action-recog-applab/cpp_server/edge-impulse-sdk/CMSIS/DSP/Include/dsp/complex_math_functions_f16.h
A	week2/action-recog-applab/cpp_server/edge-impulse-sdk/CMSIS/DSP/Include/dsp/controller_functions.h
A	week2/action-recog-applab/cpp_server/edge-impulse-sdk/CMSIS/DSP/Include/dsp/controller_functions_f16.h
A	week2/action-recog-applab/cpp_server/edge-impulse-sdk/CMSIS/DSP/Include/dsp/debug.h
A	week2/action-recog-applab/cpp_server/edge-impulse-sdk/CMSIS/DSP/Include/dsp/distance_functions.h
A	week2/action-recog-applab/cpp_server/edge-impulse-sdk/CMSIS/DSP/Include/dsp/distance_functions_f16.h
A	week2/action-recog-applab/cpp_server/edge-impulse-sdk/CMSIS/DSP/Include/dsp/fast_math_functions.h
A	week2/action-recog-applab/cpp_server/edge-impulse-sdk/CMSIS/DSP/Include/dsp/fast_math_functions_f16.h
A	week2/action-recog-applab/cpp_server/edge-impulse-sdk/CMSIS/DSP/Include/dsp/filtering_functions.h
A	week2/action-recog-applab/cpp_server/edge-impulse-sdk/CMSIS/DSP/Include/dsp/filtering_functions_f16.h
A	week2/action-recog-applab/cpp_server/edge-impulse-sdk/CMSIS/DSP/Include/dsp/interpolation_functions.h
A	week2/action-recog-applab/cpp_server/edge-impulse-sdk/CMSIS/DSP/Include/dsp/interpolation_functions_f16.h
A	week2/action-recog-applab/cpp_server/edge-impulse-sdk/CMSIS/DSP/Include/dsp/matrix_functions.h
A	week2/action-recog-applab/cpp_server/edge-impulse-sdk/CMSIS/DSP/Include/dsp/matrix_functions_f16.h
A	week2/action-recog-applab/cpp_server/edge-impulse-sdk/CMSIS/DSP/Include/dsp/matrix_utils.h
A	week2/action-recog-applab/cpp_server/edge-impulse-sdk/CMSIS/DSP/Include/dsp/none.h
A	week2/action-recog-applab/cpp_server/edge-impulse-sdk/CMSIS/DSP/Include/dsp/quaternion_math_functions.h
A	week2/action-recog-applab/cpp_server/edge-impulse-sdk/CMSIS/DSP/Include/dsp/statistics_functions.h
A	week2/action-recog-applab/cpp_server/edge-impulse-sdk/CMSIS/DSP/Include/dsp/statistics_functions_f16.h
A	week2/action-recog-applab/cpp_server/edge-impulse-sdk/CMSIS/DSP/Include/dsp/support_functions.h
A	week2/action-recog-applab/cpp_server/edge-impulse-sdk/CMSIS/DSP/Include/dsp/support_functions_f16.h
A	week2/action-recog-applab/cpp_server/edge-impulse-sdk/CMSIS/DSP/Include/dsp/svm_defines.h
A	week2/action-recog-applab/cpp_server/edge-impulse-sdk/CMSIS/DSP/Include/dsp/svm_functions.h
A	week2/action-recog-applab/cpp_server/edge-impulse-sdk/CMSIS/DSP/Include/dsp/svm_functions_f16.h
A	week2/action-recog-applab/cpp_server/edge-impulse-sdk/CMSIS/DSP/Include/dsp/transform_functions.h
A	week2/action-recog-applab/cpp_server/edge-impulse-sdk/CMSIS/DSP/Include/dsp/transform_functions_f16.h
A	week2/action-recog-applab/cpp_server/edge-impulse-sdk/CMSIS/DSP/Include/dsp/utils.h
A	week2/action-recog-applab/cpp_server/edge-impulse-sdk/CMSIS/DSP/PrivateInclude/README.md
A	week2/action-recog-applab/cpp_server/edge-impulse-sdk/CMSIS/DSP/Source/BasicMathFunctions/arm_abs_f16.c
A	week2/action-recog-applab/cpp_server/edge-impulse-sdk/CMSIS/DSP/Source/BasicMathFunctions/arm_abs_f32.c
A	week2/action-recog-applab/cpp_server/edge-impulse-sdk/CMSIS/DSP/Source/BasicMathFunctions/arm_abs_f64.c
A	week2/action-recog-applab/cpp_server/edge-impulse-sdk/CMSIS/DSP/Source/BasicMathFunctions/arm_abs_q15.c
A	week2/action-recog-applab/cpp_server/edge-impulse-sdk/CMSIS/DSP/Source/BasicMathFunctions/arm_abs_q31.c
A	week2/action-recog-applab/cpp_server/edge-impulse-sdk/CMSIS/DSP/Source/BasicMathFunctions/arm_abs_q7.c
A	week2/action-recog-applab/cpp_server/edge-impulse-sdk/CMSIS/DSP/Source/BasicMathFunctions/arm_add_f16.c
A	week2/action-recog-applab/cpp_server/edge-impulse-sdk/CMSIS/DSP/Source/BasicMathFunctions/arm_add_f32.c
A	week2/action-recog-applab/cpp_server/edge-impulse-sdk/CMSIS/DSP/Source/BasicMathFunctions/arm_add_f64.c
A	week2/action-recog-applab/cpp_server/edge-impulse-sdk/CMSIS/DSP/Source/BasicMathFunctions/arm_add_q15.c
A	week2/action-recog-applab/cpp_server/edge-impulse-sdk/CMSIS/DSP/Source/BasicMathFunctions/arm_add_q31.c
A	week2/action-recog-applab/cpp_server/edge-impulse-sdk/CMSIS/DSP/Source/BasicMathFunctions/arm_add_q7.c
A	week2/action-recog-applab/cpp_server/edge-impulse-sdk/CMSIS/DSP/Source/BasicMathFunctions/arm_and_u16.c
A	week2/action-recog-applab/cpp_server/edge-impulse-sdk/CMSIS/DSP/Source/BasicMathFunctions/arm_and_u32.c
A	week2/action-recog-applab/cpp_server/edge-impulse-sdk/CMSIS/DSP/Source/BasicMathFunctions/arm_and_u8.c
A	week2/action-recog-applab/cpp_server/edge-impulse-sdk/CMSIS/DSP/Source/BasicMathFunctions/arm_clip_f16.c
A	week2/action-recog-applab/cpp_server/edge-impulse-sdk/CMSIS/DSP/Source/BasicMathFunctions/arm_clip_f32.c
A	week2/action-recog-applab/cpp_server/edge-impulse-sdk/CMSIS/DSP/Source/BasicMathFunctions/arm_clip_q15.c
A	week2/action-recog-applab/cpp_server/edge-impulse-sdk/CMSIS/DSP/Source/BasicMathFunctions/arm_clip_q31.c
A	week2/action-recog-applab/cpp_server/edge-impulse-sdk/CMSIS/DSP/Source/BasicMathFunctions/arm_clip_q7.c
A	week2/action-recog-applab/cpp_server/edge-impulse-sdk/CMSIS/DSP/Source/BasicMathFunctions/arm_dot_prod_f16.c
A	week2/action-recog-applab/cpp_server/edge-impulse-sdk/CMSIS/DSP/Source/BasicMathFunctions/arm_dot_prod_f32.c
A	week2/action-recog-applab/cpp_server/edge-impulse-sdk/CMSIS/DSP/Source/BasicMathFunctions/arm_dot_prod_f64.c
A	week2/action-recog-applab/cpp_server/edge-impulse-sdk/CMSIS/DSP/Source/BasicMathFunctions/arm_dot_prod_q15.c
A	week2/action-recog-applab/cpp_server/edge-impulse-sdk/CMSIS/DSP/Source/BasicMathFunctions/arm_dot_prod_q31.c
A	week2/action-recog-applab/cpp_server/edge-impulse-sdk/CMSIS/DSP/Source/BasicMathFunctions/arm_dot_prod_q7.c
A	week2/action-recog-applab/cpp_server/edge-impulse-sdk/CMSIS/DSP/Source/BasicMathFunctions/arm_mult_f16.c
A	week2/action-recog-applab/cpp_server/edge-impulse-sdk/CMSIS/DSP/Source/BasicMathFunctions/arm_mult_f32.c
A	week2/action-recog-applab/cpp_server/edge-impulse-sdk/CMSIS/DSP/Source/BasicMathFunctions/arm_mult_f64.c
A	week2/action-recog-applab/cpp_server/edge-impulse-sdk/CMSIS/DSP/Source/BasicMathFunctions/arm_mult_q15.c
A	week2/action-recog-applab/cpp_server/edge-impulse-sdk/CMSIS/DSP/Source/BasicMathFunctions/arm_mult_q31.c
A	week2/action-recog-applab/cpp_server/edge-impulse-sdk/CMSIS/DSP/Source/BasicMathFunctions/arm_mult_q7.c
A	week2/action-recog-applab/cpp_server/edge-impulse-sdk/CMSIS/DSP/Source/BasicMathFunctions/arm_negate_f16.c
A	week2/action-recog-applab/cpp_server/edge-impulse-sdk/CMSIS/DSP/Source/BasicMathFunctions/arm_negate_f32.c
A	week2/action-recog-applab/cpp_server/edge-impulse-sdk/CMSIS/DSP/Source/BasicMathFunctions/arm_negate_f64.c
A	week2/action-recog-applab/cpp_server/edge-impulse-sdk/CMSIS/DSP/Source/BasicMathFunctions/arm_negate_q15.c
A	week2/action-recog-applab/cpp_server/edge-impulse-sdk/CMSIS/DSP/Source/BasicMathFunctions/arm_negate_q31.c
A	week2/action-recog-applab/cpp_server/edge-impulse-sdk/CMSIS/DSP/Source/BasicMathFunctions/arm_negate_q7.c
A	week2/action-recog-applab/cpp_server/edge-impulse-sdk/CMSIS/DSP/Source/BasicMathFunctions/arm_not_u16.c
A	week2/action-recog-applab/cpp_server/edge-impulse-sdk/CMSIS/DSP/Source/BasicMathFunctions/arm_not_u32.c
A	week2/action-recog-applab/cpp_server/edge-impulse-sdk/CMSIS/DSP/Source/BasicMathFunctions/arm_not_u8.c
A	week2/action-recog-applab/cpp_server/edge-impulse-sdk/CMSIS/DSP/Source/BasicMathFunctions/arm_offset_f16.c
A	week2/action-recog-applab/cpp_server/edge-impulse-sdk/CMSIS/DSP/Source/BasicMathFunctions/arm_offset_f32.c
A	week2/action-recog-applab/cpp_server/edge-impulse-sdk/CMSIS/DSP/Source/BasicMathFunctions/arm_offset_f64.c
A	week2/action-recog-applab/cpp_server/edge-impulse-sdk/CMSIS/DSP/Source/BasicMathFunctions/arm_offset_q15.c
A	week2/action-recog-applab/cpp_server/edge-impulse-sdk/CMSIS/DSP/Source/BasicMathFunctions/arm_offset_q31.c
A	week2/action-recog-applab/cpp_server/edge-impulse-sdk/CMSIS/DSP/Source/BasicMathFunctions/arm_offset_q7.c
A	week2/action-recog-applab/cpp_server/edge-impulse-sdk/CMSIS/DSP/Source/BasicMathFunctions/arm_or_u16.c
A	week2/action-recog-applab/cpp_server/edge-impulse-sdk/CMSIS/DSP/Source/BasicMathFunctions/arm_or_u32.c
A	week2/action-recog-applab/cpp_server/edge-impulse-sdk/CMSIS/DSP/Source/BasicMathFunctions/arm_or_u8.c
A	week2/action-recog-applab/cpp_server/edge-impulse-sdk/CMSIS/DSP/Source/BasicMathFunctions/arm_scale_f16.c
A	week2/action-recog-applab/cpp_server/edge-impulse-sdk/CMSIS/DSP/Source/BasicMathFunctions/arm_scale_f32.c
A	week2/action-recog-applab/cpp_server/edge-impulse-sdk/CMSIS/DSP/Source/BasicMathFunctions/arm_scale_f64.c
A	week2/action-recog-applab/cpp_server/edge-impulse-sdk/CMSIS/DSP/Source/BasicMathFunctions/arm_scale_q15.c
A	week2/action-recog-applab/cpp_server/edge-impulse-sdk/CMSIS/DSP/Source/BasicMathFunctions/arm_scale_q31.c
A	week2/action-recog-applab/cpp_server/edge-impulse-sdk/CMSIS/DSP/Source/BasicMathFunctions/arm_scale_q7.c
A	week2/action-recog-applab/cpp_server/edge-impulse-sdk/CMSIS/DSP/Source/BasicMathFunctions/arm_shift_q15.c
A	week2/action-recog-applab/cpp_server/edge-impulse-sdk/CMSIS/DSP/Source/BasicMathFunctions/arm_shift_q31.c
A	week2/action-recog-applab/cpp_server/edge-impulse-sdk/CMSIS/DSP/Source/BasicMathFunctions/arm_shift_q7.c
A	week2/action-recog-applab/cpp_server/edge-impulse-sdk/CMSIS/DSP/Source/BasicMathFunctions/arm_sub_f16.c
A	week2/action-recog-applab/cpp_server/edge-impulse-sdk/CMSIS/DSP/Source/BasicMathFunctions/arm_sub_f32.c
A	week2/action-recog-applab/cpp_server/edge-impulse-sdk/CMSIS/DSP/Source/BasicMathFunctions/arm_sub_f64.c
A	week2/action-recog-applab/cpp_server/edge-impulse-sdk/CMSIS/DSP/Source/BasicMathFunctions/arm_sub_q15.c
A	week2/action-recog-applab/cpp_server/edge-impulse-sdk/CMSIS/DSP/Source/BasicMathFunctions/arm_sub_q31.c
A	week2/action-recog-applab/cpp_server/edge-impulse-sdk/CMSIS/DSP/Source/BasicMathFunctions/arm_sub_q7.c
A	week2/action-recog-applab/cpp_server/edge-impulse-sdk/CMSIS/DSP/Source/BasicMathFunctions/arm_xor_u16.c
A	week2/action-recog-applab/cpp_server/edge-impulse-sdk/CMSIS/DSP/Source/BasicMathFunctions/arm_xor_u32.c
A	week2/action-recog-applab/cpp_server/edge-impulse-sdk/CMSIS/DSP/Source/BasicMathFunctions/arm_xor_u8.c
A	week2/action-recog-applab/cpp_server/edge-impulse-sdk/CMSIS/DSP/Source/BayesFunctions/arm_gaussian_naive_bayes_predict_f16.c
A	week2/action-recog-applab/cpp_server/edge-impulse-sdk/CMSIS/DSP/Source/BayesFunctions/arm_gaussian_naive_bayes_predict_f32.c
A	week2/action-recog-applab/cpp_server/edge-impulse-sdk/CMSIS/DSP/Source/CommonTables/arm_common_tables.c
A	week2/action-recog-applab/cpp_server/edge-impulse-sdk/CMSIS/DSP/Source/CommonTables/arm_common_tables_f16.c
A	week2/action-recog-applab/cpp_server/edge-impulse-sdk/CMSIS/DSP/Source/CommonTables/arm_const_structs.c
A	week2/action-recog-applab/cpp_server/edge-impulse-sdk/CMSIS/DSP/Source/CommonTables/arm_const_structs_f16.c
A	week2/action-recog-applab/cpp_server/edge-impulse-sdk/CMSIS/DSP/Source/CommonTables/arm_mve_tables.c
A	week2/action-recog-applab/cpp_server/edge-impulse-sdk/CMSIS/DSP/Source/CommonTables/arm_mve_tables_f16.c
A	week2/action-recog-applab/cpp_server/edge-impulse-sdk/CMSIS/DSP/Source/ComplexMathFunctions/arm_cmplx_conj_f16.c
A	week2/action-recog-applab/cpp_server/edge-impulse-sdk/CMSIS/DSP/Source/ComplexMathFunctions/arm_cmplx_conj_f32.c
A	week2/action-recog-applab/cpp_server/edge-impulse-sdk/CMSIS/DSP/Source/ComplexMathFunctions/arm_cmplx_conj_q15.c
A	week2/action-recog-applab/cpp_server/edge-impulse-sdk/CMSIS/DSP/Source/ComplexMathFunctions/arm_cmplx_conj_q31.c
A	week2/action-recog-applab/cpp_server/edge-impulse-sdk/CMSIS/DSP/Source/ComplexMathFunctions/arm_cmplx_dot_prod_f16.c
A	week2/action-recog-applab/cpp_server/edge-impulse-sdk/CMSIS/DSP/Source/ComplexMathFunctions/arm_cmplx_dot_prod_f32.c
A	week2/action-recog-applab/cpp_server/edge-impulse-sdk/CMSIS/DSP/Source/ComplexMathFunctions/arm_cmplx_dot_prod_q15.c
A	week2/action-recog-applab/cpp_server/edge-impulse-sdk/CMSIS/DSP/Source/ComplexMathFunctions/arm_cmplx_dot_prod_q31.c
A	week2/action-recog-applab/cpp_server/edge-impulse-sdk/CMSIS/DSP/Source/ComplexMathFunctions/arm_cmplx_mag_f16.c
A	week2/action-recog-applab/cpp_server/edge-impulse-sdk/CMSIS/DSP/Source/ComplexMathFunctions/arm_cmplx_mag_f32.c
A	week2/action-recog-applab/cpp_server/edge-impulse-sdk/CMSIS/DSP/Source/ComplexMathFunctions/arm_cmplx_mag_f64.c
A	week2/action-recog-applab/cpp_server/edge-impulse-sdk/CMSIS/DSP/Source/ComplexMathFunctions/arm_cmplx_mag_fast_q15.c
A	week2/action-recog-applab/cpp_server/edge-impulse-sdk/CMSIS/DSP/Source/ComplexMathFunctions/arm_cmplx_mag_q15.c
A	week2/action-recog-applab/cpp_server/edge-impulse-sdk/CMSIS/DSP/Source/ComplexMathFunctions/arm_cmplx_mag_q31.c
A	week2/action-recog-applab/cpp_server/edge-impulse-sdk/CMSIS/DSP/Source/ComplexMathFunctions/arm_cmplx_mag_squared_f16.c
A	week2/action-recog-applab/cpp_server/edge-impulse-sdk/CMSIS/DSP/Source/ComplexMathFunctions/arm_cmplx_mag_squared_f32.c
A	week2/action-recog-applab/cpp_server/edge-impulse-sdk/CMSIS/DSP/Source/ComplexMathFunctions/arm_cmplx_mag_squared_f64.c
A	week2/action-recog-applab/cpp_server/edge-impulse-sdk/CMSIS/DSP/Source/ComplexMathFunctions/arm_cmplx_mag_squared_q15.c
A	week2/action-recog-applab/cpp_server/edge-impulse-sdk/CMSIS/DSP/Source/ComplexMathFunctions/arm_cmplx_mag_squared_q31.c
A	week2/action-recog-applab/cpp_server/edge-impulse-sdk/CMSIS/DSP/Source/ComplexMathFunctions/arm_cmplx_mult_cmplx_f16.c
A	week2/action-recog-applab/cpp_server/edge-impulse-sdk/CMSIS/DSP/Source/ComplexMathFunctions/arm_cmplx_mult_cmplx_f32.c
A	week2/action-recog-applab/cpp_server/edge-impulse-sdk/CMSIS/DSP/Source/ComplexMathFunctions/arm_cmplx_mult_cmplx_f64.c
A	week2/action-recog-applab/cpp_server/edge-impulse-sdk/CMSIS/DSP/Source/ComplexMathFunctions/arm_cmplx_mult_cmplx_q15.c
A	week2/action-recog-applab/cpp_server/edge-impulse-sdk/CMSIS/DSP/Source/ComplexMathFunctions/arm_cmplx_mult_cmplx_q31.c
A	week2/action-recog-applab/cpp_server/edge-impulse-sdk/CMSIS/DSP/Source/ComplexMathFunctions/arm_cmplx_mult_real_f16.c
A	week2/action-recog-applab/cpp_server/edge-impulse-sdk/CMSIS/DSP/Source/ComplexMathFunctions/arm_cmplx_mult_real_f32.c
A	week2/action-recog-applab/cpp_server/edge-impulse-sdk/CMSIS/DSP/Source/ComplexMathFunctions/arm_cmplx_mult_real_q15.c
A	week2/action-recog-applab/cpp_server/edge-impulse-sdk/CMSIS/DSP/Source/ComplexMathFunctions/arm_cmplx_mult_real_q31.c
A	week2/action-recog-applab/cpp_server/edge-impulse-sdk/CMSIS/DSP/Source/ControllerFunctions/arm_pid_init_f32.c
A	week2/action-recog-applab/cpp_server/edge-impulse-sdk/CMSIS/DSP/Source/ControllerFunctions/arm_pid_init_q15.c
A	week2/action-recog-applab/cpp_server/edge-impulse-sdk/CMSIS/DSP/Source/ControllerFunctions/arm_pid_init_q31.c
A	week2/action-recog-applab/cpp_server/edge-impulse-sdk/CMSIS/DSP/Source/ControllerFunctions/arm_pid_reset_f32.c
A	week2/action-recog-applab/cpp_server/edge-impulse-sdk/CMSIS/DSP/Source/ControllerFunctions/arm_pid_reset_q15.c
A	week2/action-recog-applab/cpp_server/edge-impulse-sdk/CMSIS/DSP/Source/ControllerFunctions/arm_pid_reset_q31.c
A	week2/action-recog-applab/cpp_server/edge-impulse-sdk/CMSIS/DSP/Source/ControllerFunctions/arm_sin_cos_f32.c
A	week2/action-recog-applab/cpp_server/edge-impulse-sdk/CMSIS/DSP/Source/ControllerFunctions/arm_sin_cos_q31.c
A	week2/action-recog-applab/cpp_server/edge-impulse-sdk/CMSIS/DSP/Source/DistanceFunctions/arm_boolean_distance.c
A	week2/action-recog-applab/cpp_server/edge-impulse-sdk/CMSIS/DSP/Source/DistanceFunctions/arm_boolean_distance_template.h
A	week2/action-recog-applab/cpp_server/edge-impulse-sdk/CMSIS/DSP/Source/DistanceFunctions/arm_braycurtis_distance_f16.c
A	week2/action-recog-applab/cpp_server/edge-impulse-sdk/CMSIS/DSP/Source/DistanceFunctions/arm_braycurtis_distance_f32.c
A	week2/action-recog-applab/cpp_server/edge-impulse-sdk/CMSIS/DSP/Source/DistanceFunctions/arm_canberra_distance_f16.c
A	week2/action-recog-applab/cpp_server/edge-impulse-sdk/CMSIS/DSP/Source/DistanceFunctions/arm_canberra_distance_f32.c
A	week2/action-recog-applab/cpp_server/edge-impulse-sdk/CMSIS/DSP/Source/DistanceFunctions/arm_chebyshev_distance_f16.c
A	week2/action-recog-applab/cpp_server/edge-impulse-sdk/CMSIS/DSP/Source/DistanceFunctions/arm_chebyshev_distance_f32.c
A	week2/action-recog-applab/cpp_server/edge-impulse-sdk/CMSIS/DSP/Source/DistanceFunctions/arm_chebyshev_distance_f64.c
A	week2/action-recog-applab/cpp_server/edge-impulse-sdk/CMSIS/DSP/Source/DistanceFunctions/arm_cityblock_distance_f16.c
A	week2/action-recog-applab/cpp_server/edge-impulse-sdk/CMSIS/DSP/Source/DistanceFunctions/arm_cityblock_distance_f32.c
A	week2/action-recog-applab/cpp_server/edge-impulse-sdk/CMSIS/DSP/Source/DistanceFunctions/arm_cityblock_distance_f64.c
A	week2/action-recog-applab/cpp_server/edge-impulse-sdk/CMSIS/DSP/Source/DistanceFunctions/arm_correlation_distance_f16.c
A	week2/action-recog-applab/cpp_server/edge-impulse-sdk/CMSIS/DSP/Source/DistanceFunctions/arm_correlation_distance_f32.c
A	week2/action-recog-applab/cpp_server/edge-impulse-sdk/CMSIS/DSP/Source/DistanceFunctions/arm_cosine_distance_f16.c
A	week2/action-recog-applab/cpp_server/edge-impulse-sdk/CMSIS/DSP/Source/DistanceFunctions/arm_cosine_distance_f32.c
A	week2/action-recog-applab/cpp_server/edge-impulse-sdk/CMSIS/DSP/Source/DistanceFunctions/arm_cosine_distance_f64.c
A	week2/action-recog-applab/cpp_server/edge-impulse-sdk/CMSIS/DSP/Source/DistanceFunctions/arm_dice_distance.c
A	week2/action-recog-applab/cpp_server/edge-impulse-sdk/CMSIS/DSP/Source/DistanceFunctions/arm_euclidean_distance_f16.c
A	week2/action-recog-applab/cpp_server/edge-impulse-sdk/CMSIS/DSP/Source/DistanceFunctions/arm_euclidean_distance_f32.c
A	week2/action-recog-applab/cpp_server/edge-impulse-sdk/CMSIS/DSP/Source/DistanceFunctions/arm_euclidean_distance_f64.c
A	week2/action-recog-applab/cpp_server/edge-impulse-sdk/CMSIS/DSP/Source/DistanceFunctions/arm_hamming_distance.c
A	week2/action-recog-applab/cpp_server/edge-impulse-sdk/CMSIS/DSP/Source/DistanceFunctions/arm_jaccard_distance.c
A	week2/action-recog-applab/cpp_server/edge-impulse-sdk/CMSIS/DSP/Source/DistanceFunctions/arm_jensenshannon_distance_f16.c
A	week2/action-recog-applab/cpp_server/edge-impulse-sdk/CMSIS/DSP/Source/DistanceFunctions/arm_jensenshannon_distance_f32.c
A	week2/action-recog-applab/cpp_server/edge-impulse-sdk/CMSIS/DSP/Source/DistanceFunctions/arm_kulsinski_distance.c
A	week2/action-recog-applab/cpp_server/edge-impulse-sdk/CMSIS/DSP/Source/DistanceFunctions/arm_minkowski_distance_f16.c
A	week2/action-recog-applab/cpp_server/edge-impulse-sdk/CMSIS/DSP/Source/DistanceFunctions/arm_minkowski_distance_f32.c
A	week2/action-recog-applab/cpp_server/edge-impulse-sdk/CMSIS/DSP/Source/DistanceFunctions/arm_rogerstanimoto_distance.c
A	week2/action-recog-applab/cpp_server/edge-impulse-sdk/CMSIS/DSP/Source/DistanceFunctions/arm_russellrao_distance.c
A	week2/action-recog-applab/cpp_server/edge-impulse-sdk/CMSIS/DSP/Source/DistanceFunctions/arm_sokalmichener_distance.c
A	week2/action-recog-applab/cpp_server/edge-impulse-sdk/CMSIS/DSP/Source/DistanceFunctions/arm_sokalsneath_distance.c
A	week2/action-recog-applab/cpp_server/edge-impulse-sdk/CMSIS/DSP/Source/DistanceFunctions/arm_yule_distance.c
A	week2/action-recog-applab/cpp_server/edge-impulse-sdk/CMSIS/DSP/Source/FastMathFunctions/arm_atan2_f16.c
A	week2/action-recog-applab/cpp_server/edge-impulse-sdk/CMSIS/DSP/Source/FastMathFunctions/arm_atan2_f32.c
A	week2/action-recog-applab/cpp_server/edge-impulse-sdk/CMSIS/DSP/Source/FastMathFunctions/arm_atan2_q15.c
A	week2/action-recog-applab/cpp_server/edge-impulse-sdk/CMSIS/DSP/Source/FastMathFunctions/arm_atan2_q31.c
A	week2/action-recog-applab/cpp_server/edge-impulse-sdk/CMSIS/DSP/Source/FastMathFunctions/arm_cos_f32.c
A	week2/action-recog-applab/cpp_server/edge-impulse-sdk/CMSIS/DSP/Source/FastMathFunctions/arm_cos_q15.c
A	week2/action-recog-applab/cpp_server/edge-impulse-sdk/CMSIS/DSP/Source/FastMathFunctions/arm_cos_q31.c
A	week2/action-recog-applab/cpp_server/edge-impulse-sdk/CMSIS/DSP/Source/FastMathFunctions/arm_divide_q15.c
A	week2/action-recog-applab/cpp_server/edge-impulse-sdk/CMSIS/DSP/Source/FastMathFunctions/arm_divide_q31.c
A	week2/action-recog-applab/cpp_server/edge-impulse-sdk/CMSIS/DSP/Source/FastMathFunctions/arm_sin_f32.c
A	week2/action-recog-applab/cpp_server/edge-impulse-sdk/CMSIS/DSP/Source/FastMathFunctions/arm_sin_q15.c
A	week2/action-recog-applab/cpp_server/edge-impulse-sdk/CMSIS/DSP/Source/FastMathFunctions/arm_sin_q31.c
A	week2/action-recog-applab/cpp_server/edge-impulse-sdk/CMSIS/DSP/Source/FastMathFunctions/arm_sqrt_q15.c
A	week2/action-recog-applab/cpp_server/edge-impulse-sdk/CMSIS/DSP/Source/FastMathFunctions/arm_sqrt_q31.c
A	week2/action-recog-applab/cpp_server/edge-impulse-sdk/CMSIS/DSP/Source/FastMathFunctions/arm_vexp_f16.c
A	week2/action-recog-applab/cpp_server/edge-impulse-sdk/CMSIS/DSP/Source/FastMathFunctions/arm_vexp_f32.c
A	week2/action-recog-applab/cpp_server/edge-impulse-sdk/CMSIS/DSP/Source/FastMathFunctions/arm_vexp_f64.c
A	week2/action-recog-applab/cpp_server/edge-impulse-sdk/CMSIS/DSP/Source/FastMathFunctions/arm_vinverse_f16.c
A	week2/action-recog-applab/cpp_server/edge-impulse-sdk/CMSIS/DSP/Source/FastMathFunctions/arm_vlog_f16.c
A	week2/action-recog-applab/cpp_server/edge-impulse-sdk/CMSIS/DSP/Source/FastMathFunctions/arm_vlog_f32.c
A	week2/action-recog-applab/cpp_server/edge-impulse-sdk/CMSIS/DSP/Source/FastMathFunctions/arm_vlog_f64.c
A	week2/action-recog-applab/cpp_server/edge-impulse-sdk/CMSIS/DSP/Source/FastMathFunctions/arm_vlog_q15.c
A	week2/action-recog-applab/cpp_server/edge-impulse-sdk/CMSIS/DSP/Source/FastMathFunctions/arm_vlog_q31.c
A	week2/action-recog-applab/cpp_server/edge-impulse-sdk/CMSIS/DSP/Source/FilteringFunctions/arm_biquad_cascade_df1_32x64_init_q31.c
A	week2/action-recog-applab/cpp_server/edge-impulse-sdk/CMSIS/DSP/Source/FilteringFunctions/arm_biquad_cascade_df1_32x64_q31.c
A	week2/action-recog-applab/cpp_server/edge-impulse-sdk/CMSIS/DSP/Source/FilteringFunctions/arm_biquad_cascade_df1_f16.c
A	week2/action-recog-applab/cpp_server/edge-impulse-sdk/CMSIS/DSP/Source/FilteringFunctions/arm_biquad_cascade_df1_f32.c
A	week2/action-recog-applab/cpp_server/edge-impulse-sdk/CMSIS/DSP/Source/FilteringFunctions/arm_biquad_cascade_df1_fast_q15.c
A	week2/action-recog-applab/cpp_server/edge-impulse-sdk/CMSIS/DSP/Source/FilteringFunctions/arm_biquad_cascade_df1_fast_q31.c
A	week2/action-recog-applab/cpp_server/edge-impulse-sdk/CMSIS/DSP/Source/FilteringFunctions/arm_biquad_cascade_df1_init_f16.c
A	week2/action-recog-applab/cpp_server/edge-impulse-sdk/CMSIS/DSP/Source/FilteringFunctions/arm_biquad_cascade_df1_init_f32.c
A	week2/action-recog-applab/cpp_server/edge-impulse-sdk/CMSIS/DSP/Source/FilteringFunctions/arm_biquad_cascade_df1_init_q15.c
A	week2/action-recog-applab/cpp_server/edge-impulse-sdk/CMSIS/DSP/Source/FilteringFunctions/arm_biquad_cascade_df1_init_q31.c
A	week2/action-recog-applab/cpp_server/edge-impulse-sdk/CMSIS/DSP/Source/FilteringFunctions/arm_biquad_cascade_df1_q15.c
A	week2/action-recog-applab/cpp_server/edge-impulse-sdk/CMSIS/DSP/Source/FilteringFunctions/arm_biquad_cascade_df1_q31.c
A	week2/action-recog-applab/cpp_server/edge-impulse-sdk/CMSIS/DSP/Source/FilteringFunctions/arm_biquad_cascade_df2T_f16.c
A	week2/action-recog-applab/cpp_server/edge-impulse-sdk/CMSIS/DSP/Source/FilteringFunctions/arm_biquad_cascade_df2T_f32.c
A	week2/action-recog-applab/cpp_server/edge-impulse-sdk/CMSIS/DSP/Source/FilteringFunctions/arm_biquad_cascade_df2T_f64.c
A	week2/action-recog-applab/cpp_server/edge-impulse-sdk/CMSIS/DSP/Source/FilteringFunctions/arm_biquad_cascade_df2T_init_f16.c
A	week2/action-recog-applab/cpp_server/edge-impulse-sdk/CMSIS/DSP/Source/FilteringFunctions/arm_biquad_cascade_df2T_init_f32.c
A	week2/action-recog-applab/cpp_server/edge-impulse-sdk/CMSIS/DSP/Source/FilteringFunctions/arm_biquad_cascade_df2T_init_f64.c
A	week2/action-recog-applab/cpp_server/edge-impulse-sdk/CMSIS/DSP/Source/FilteringFunctions/arm_biquad_cascade_stereo_df2T_f16.c
A	week2/action-recog-applab/cpp_server/edge-impulse-sdk/CMSIS/DSP/Source/FilteringFunctions/arm_biquad_cascade_stereo_df2T_f32.c
A	week2/action-recog-applab/cpp_server/edge-impulse-sdk/CMSIS/DSP/Source/FilteringFunctions/arm_biquad_cascade_stereo_df2T_init_f16.c
A	week2/action-recog-applab/cpp_server/edge-impulse-sdk/CMSIS/DSP/Source/FilteringFunctions/arm_biquad_cascade_stereo_df2T_init_f32.c
A	week2/action-recog-applab/cpp_server/edge-impulse-sdk/CMSIS/DSP/Source/FilteringFunctions/arm_conv_f32.c
A	week2/action-recog-applab/cpp_server/edge-impulse-sdk/CMSIS/DSP/Source/FilteringFunctions/arm_conv_fast_opt_q15.c
A	week2/action-recog-applab/cpp_server/edge-impulse-sdk/CMSIS/DSP/Source/FilteringFunctions/arm_conv_fast_q15.c
A	week2/action-recog-applab/cpp_server/edge-impulse-sdk/CMSIS/DSP/Source/FilteringFunctions/arm_conv_fast_q31.c
A	week2/action-recog-applab/cpp_server/edge-impulse-sdk/CMSIS/DSP/Source/FilteringFunctions/arm_conv_opt_q15.c
A	week2/action-recog-applab/cpp_server/edge-impulse-sdk/CMSIS/DSP/Source/FilteringFunctions/arm_conv_opt_q7.c
A	week2/action-recog-applab/cpp_server/edge-impulse-sdk/CMSIS/DSP/Source/FilteringFunctions/arm_conv_partial_f32.c
A	week2/action-recog-applab/cpp_server/edge-impulse-sdk/CMSIS/DSP/Source/FilteringFunctions/arm_conv_partial_fast_opt_q15.c
A	week2/action-recog-applab/cpp_server/edge-impulse-sdk/CMSIS/DSP/Source/FilteringFunctions/arm_conv_partial_fast_q15.c
A	week2/action-recog-applab/cpp_server/edge-impulse-sdk/CMSIS/DSP/Source/FilteringFunctions/arm_conv_partial_fast_q31.c
A	week2/action-recog-applab/cpp_server/edge-impulse-sdk/CMSIS/DSP/Source/FilteringFunctions/arm_conv_partial_opt_q15.c
A	week2/action-recog-applab/cpp_server/edge-impulse-sdk/CMSIS/DSP/Source/FilteringFunctions/arm_conv_partial_opt_q7.c
A	week2/action-recog-applab/cpp_server/edge-impulse-sdk/CMSIS/DSP/Source/FilteringFunctions/arm_conv_partial_q15.c
A	week2/action-recog-applab/cpp_server/edge-impulse-sdk/CMSIS/DSP/Source/FilteringFunctions/arm_conv_partial_q31.c
A	week2/action-recog-applab/cpp_server/edge-impulse-sdk/CMSIS/DSP/Source/FilteringFunctions/arm_conv_partial_q7.c
A	week2/action-recog-applab/cpp_server/edge-impulse-sdk/CMSIS/DSP/Source/FilteringFunctions/arm_conv_q15.c
A	week2/action-recog-applab/cpp_server/edge-impulse-sdk/CMSIS/DSP/Source/FilteringFunctions/arm_conv_q31.c
A	week2/action-recog-applab/cpp_server/edge-impulse-sdk/CMSIS/DSP/Source/FilteringFunctions/arm_conv_q7.c
A	week2/action-recog-applab/cpp_server/edge-impulse-sdk/CMSIS/DSP/Source/FilteringFunctions/arm_correlate_f16.c
A	week2/action-recog-applab/cpp_server/edge-impulse-sdk/CMSIS/DSP/Source/FilteringFunctions/arm_correlate_f32.c
A	week2/action-recog-applab/cpp_server/edge-impulse-sdk/CMSIS/DSP/Source/FilteringFunctions/arm_correlate_f64.c
A	week2/action-recog-applab/cpp_server/edge-impulse-sdk/CMSIS/DSP/Source/FilteringFunctions/arm_correlate_fast_opt_q15.c
A	week2/action-recog-applab/cpp_server/edge-impulse-sdk/CMSIS/DSP/Source/FilteringFunctions/arm_correlate_fast_q15.c
A	week2/action-recog-applab/cpp_server/edge-impulse-sdk/CMSIS/DSP/Source/FilteringFunctions/arm_correlate_fast_q31.c
A	week2/action-recog-applab/cpp_server/edge-impulse-sdk/CMSIS/DSP/Source/FilteringFunctions/arm_correlate_opt_q15.c
A	week2/action-recog-applab/cpp_server/edge-impulse-sdk/CMSIS/DSP/Source/FilteringFunctions/arm_correlate_opt_q7.c
A	week2/action-recog-applab/cpp_server/edge-impulse-sdk/CMSIS/DSP/Source/FilteringFunctions/arm_correlate_q15.c
A	week2/action-recog-applab/cpp_server/edge-impulse-sdk/CMSIS/DSP/Source/FilteringFunctions/arm_correlate_q31.c
A	week2/action-recog-applab/cpp_server/edge-impulse-sdk/CMSIS/DSP/Source/FilteringFunctions/arm_correlate_q7.c
A	week2/action-recog-applab/cpp_server/edge-impulse-sdk/CMSIS/DSP/Source/FilteringFunctions/arm_fir_decimate_f32.c
A	week2/action-recog-applab/cpp_server/edge-impulse-sdk/CMSIS/DSP/Source/FilteringFunctions/arm_fir_decimate_fast_q15.c
A	week2/action-recog-applab/cpp_server/edge-impulse-sdk/CMSIS/DSP/Source/FilteringFunctions/arm_fir_decimate_fast_q31.c
A	week2/action-recog-applab/cpp_server/edge-impulse-sdk/CMSIS/DSP/Source/FilteringFunctions/arm_fir_decimate_init_f32.c
A	week2/action-recog-applab/cpp_server/edge-impulse-sdk/CMSIS/DSP/Source/FilteringFunctions/arm_fir_decimate_init_q15.c
A	week2/action-recog-applab/cpp_server/edge-impulse-sdk/CMSIS/DSP/Source/FilteringFunctions/arm_fir_decimate_init_q31.c
A	week2/action-recog-applab/cpp_server/edge-impulse-sdk/CMSIS/DSP/Source/FilteringFunctions/arm_fir_decimate_q15.c
A	week2/action-recog-applab/cpp_server/edge-impulse-sdk/CMSIS/DSP/Source/FilteringFunctions/arm_fir_decimate_q31.c
A	week2/action-recog-applab/cpp_server/edge-impulse-sdk/CMSIS/DSP/Source/FilteringFunctions/arm_fir_f16.c
A	week2/action-recog-applab/cpp_server/edge-impulse-sdk/CMSIS/DSP/Source/FilteringFunctions/arm_fir_f32.c
A	week2/action-recog-applab/cpp_server/edge-impulse-sdk/CMSIS/DSP/Source/FilteringFunctions/arm_fir_f64.c
A	week2/action-recog-applab/cpp_server/edge-impulse-sdk/CMSIS/DSP/Source/FilteringFunctions/arm_fir_fast_q15.c
A	week2/action-recog-applab/cpp_server/edge-impulse-sdk/CMSIS/DSP/Source/FilteringFunctions/arm_fir_fast_q31.c
A	week2/action-recog-applab/cpp_server/edge-impulse-sdk/CMSIS/DSP/Source/FilteringFunctions/arm_fir_init_f16.c
A	week2/action-recog-applab/cpp_server/edge-impulse-sdk/CMSIS/DSP/Source/FilteringFunctions/arm_fir_init_f32.c
A	week2/action-recog-applab/cpp_server/edge-impulse-sdk/CMSIS/DSP/Source/FilteringFunctions/arm_fir_init_f64.c
A	week2/action-recog-applab/cpp_server/edge-impulse-sdk/CMSIS/DSP/Source/FilteringFunctions/arm_fir_init_q15.c
A	week2/action-recog-applab/cpp_server/edge-impulse-sdk/CMSIS/DSP/Source/FilteringFunctions/arm_fir_init_q31.c
A	week2/action-recog-applab/cpp_server/edge-impulse-sdk/CMSIS/DSP/Source/FilteringFunctions/arm_fir_init_q7.c
A	week2/action-recog-applab/cpp_server/edge-impulse-sdk/CMSIS/DSP/Source/FilteringFunctions/arm_fir_interpolate_f32.c
A	week2/action-recog-applab/cpp_server/edge-impulse-sdk/CMSIS/DSP/Source/FilteringFunctions/arm_fir_interpolate_init_f32.c
A	week2/action-recog-applab/cpp_server/edge-impulse-sdk/CMSIS/DSP/Source/FilteringFunctions/arm_fir_interpolate_init_q15.c
A	week2/action-recog-applab/cpp_server/edge-impulse-sdk/CMSIS/DSP/Source/FilteringFunctions/arm_fir_interpolate_init_q31.c
A	week2/action-recog-applab/cpp_server/edge-impulse-sdk/CMSIS/DSP/Source/FilteringFunctions/arm_fir_interpolate_q15.c
A	week2/action-recog-applab/cpp_server/edge-impulse-sdk/CMSIS/DSP/Source/FilteringFunctions/arm_fir_interpolate_q31.c
A	week2/action-recog-applab/cpp_server/edge-impulse-sdk/CMSIS/DSP/Source/FilteringFunctions/arm_fir_lattice_f32.c
A	week2/action-recog-applab/cpp_server/edge-impulse-sdk/CMSIS/DSP/Source/FilteringFunctions/arm_fir_lattice_init_f32.c
A	week2/action-recog-applab/cpp_server/edge-impulse-sdk/CMSIS/DSP/Source/FilteringFunctions/arm_fir_lattice_init_q15.c
A	week2/action-recog-applab/cpp_server/edge-impulse-sdk/CMSIS/DSP/Source/FilteringFunctions/arm_fir_lattice_init_q31.c
A	week2/action-recog-applab/cpp_server/edge-impulse-sdk/CMSIS/DSP/Source/FilteringFunctions/arm_fir_lattice_q15.c
A	week2/action-recog-applab/cpp_server/edge-impulse-sdk/CMSIS/DSP/Source/FilteringFunctions/arm_fir_lattice_q31.c
A	week2/action-recog-applab/cpp_server/edge-impulse-sdk/CMSIS/DSP/Source/FilteringFunctions/arm_fir_q15.c
A	week2/action-recog-applab/cpp_server/edge-impulse-sdk/CMSIS/DSP/Source/FilteringFunctions/arm_fir_q31.c
A	week2/action-recog-applab/cpp_server/edge-impulse-sdk/CMSIS/DSP/Source/FilteringFunctions/arm_fir_q7.c
A	week2/action-recog-applab/cpp_server/edge-impulse-sdk/CMSIS/DSP/Source/FilteringFunctions/arm_fir_sparse_f32.c
A	week2/action-recog-applab/cpp_server/edge-impulse-sdk/CMSIS/DSP/Source/FilteringFunctions/arm_fir_sparse_init_f32.c
A	week2/action-recog-applab/cpp_server/edge-impulse-sdk/CMSIS/DSP/Source/FilteringFunctions/arm_fir_sparse_init_q15.c
A	week2/action-recog-applab/cpp_server/edge-impulse-sdk/CMSIS/DSP/Source/FilteringFunctions/arm_fir_sparse_init_q31.c
A	week2/action-recog-applab/cpp_server/edge-impulse-sdk/CMSIS/DSP/Source/FilteringFunctions/arm_fir_sparse_init_q7.c
A	week2/action-recog-applab/cpp_server/edge-impulse-sdk/CMSIS/DSP/Source/FilteringFunctions/arm_fir_sparse_q15.c
A	week2/action-recog-applab/cpp_server/edge-impulse-sdk/CMSIS/DSP/Source/FilteringFunctions/arm_fir_sparse_q31.c
A	week2/action-recog-applab/cpp_server/edge-impulse-sdk/CMSIS/DSP/Source/FilteringFunctions/arm_fir_sparse_q7.c
A	week2/action-recog-applab/cpp_server/edge-impulse-sdk/CMSIS/DSP/Source/FilteringFunctions/arm_iir_lattice_f32.c
A	week2/action-recog-applab/cpp_server/edge-impulse-sdk/CMSIS/DSP/Source/FilteringFunctions/arm_iir_lattice_init_f32.c
A	week2/action-recog-applab/cpp_server/edge-impulse-sdk/CMSIS/DSP/Source/FilteringFunctions/arm_iir_lattice_init_q15.c
A	week2/action-recog-applab/cpp_server/edge-impulse-sdk/CMSIS/DSP/Source/FilteringFunctions/arm_iir_lattice_init_q31.c
A	week2/action-recog-applab/cpp_server/edge-impulse-sdk/CMSIS/DSP/Source/FilteringFunctions/arm_iir_lattice_q15.c
A	week2/action-recog-applab/cpp_server/edge-impulse-sdk/CMSIS/DSP/Source/FilteringFunctions/arm_iir_lattice_q31.c
A	week2/action-recog-applab/cpp_server/edge-impulse-sdk/CMSIS/DSP/Source/FilteringFunctions/arm_levinson_durbin_f16.c
A	week2/action-recog-applab/cpp_server/edge-impulse-sdk/CMSIS/DSP/Source/FilteringFunctions/arm_levinson_durbin_f32.c
A	week2/action-recog-applab/cpp_server/edge-impulse-sdk/CMSIS/DSP/Source/FilteringFunctions/arm_levinson_durbin_q31.c
A	week2/action-recog-applab/cpp_server/edge-impulse-sdk/CMSIS/DSP/Source/FilteringFunctions/arm_lms_f32.c
A	week2/action-recog-applab/cpp_server/edge-impulse-sdk/CMSIS/DSP/Source/FilteringFunctions/arm_lms_init_f32.c
A	week2/action-recog-applab/cpp_server/edge-impulse-sdk/CMSIS/DSP/Source/FilteringFunctions/arm_lms_init_q15.c
A	week2/action-recog-applab/cpp_server/edge-impulse-sdk/CMSIS/DSP/Source/FilteringFunctions/arm_lms_init_q31.c
A	week2/action-recog-applab/cpp_server/edge-impulse-sdk/CMSIS/DSP/Source/FilteringFunctions/arm_lms_norm_f32.c
A	week2/action-recog-applab/cpp_server/edge-impulse-sdk/CMSIS/DSP/Source/FilteringFunctions/arm_lms_norm_init_f32.c
A	week2/action-recog-applab/cpp_server/edge-impulse-sdk/CMSIS/DSP/Source/FilteringFunctions/arm_lms_norm_init_q15.c
A	week2/action-recog-applab/cpp_server/edge-impulse-sdk/CMSIS/DSP/Source/FilteringFunctions/arm_lms_norm_init_q31.c
A	week2/action-recog-applab/cpp_server/edge-impulse-sdk/CMSIS/DSP/Source/FilteringFunctions/arm_lms_norm_q15.c
A	week2/action-recog-applab/cpp_server/edge-impulse-sdk/CMSIS/DSP/Source/FilteringFunctions/arm_lms_norm_q31.c
A	week2/action-recog-applab/cpp_server/edge-impulse-sdk/CMSIS/DSP/Source/FilteringFunctions/arm_lms_q15.c
A	week2/action-recog-applab/cpp_server/edge-impulse-sdk/CMSIS/DSP/Source/FilteringFunctions/arm_lms_q31.c
A	week2/action-recog-applab/cpp_server/edge-impulse-sdk/CMSIS/DSP/Source/InterpolationFunctions/arm_bilinear_interp_f16.c
A	week2/action-recog-applab/cpp_server/edge-impulse-sdk/CMSIS/DSP/Source/InterpolationFunctions/arm_bilinear_interp_f32.c
A	week2/action-recog-applab/cpp_server/edge-impulse-sdk/CMSIS/DSP/Source/InterpolationFunctions/arm_bilinear_interp_q15.c
A	week2/action-recog-applab/cpp_server/edge-impulse-sdk/CMSIS/DSP/Source/InterpolationFunctions/arm_bilinear_interp_q31.c
A	week2/action-recog-applab/cpp_server/edge-impulse-sdk/CMSIS/DSP/Source/InterpolationFunctions/arm_bilinear_interp_q7.c
A	week2/action-recog-applab/cpp_server/edge-impulse-sdk/CMSIS/DSP/Source/InterpolationFunctions/arm_linear_interp_f16.c
A	week2/action-recog-applab/cpp_server/edge-impulse-sdk/CMSIS/DSP/Source/InterpolationFunctions/arm_linear_interp_f32.c
A	week2/action-recog-applab/cpp_server/edge-impulse-sdk/CMSIS/DSP/Source/InterpolationFunctions/arm_linear_interp_q15.c
A	week2/action-recog-applab/cpp_server/edge-impulse-sdk/CMSIS/DSP/Source/InterpolationFunctions/arm_linear_interp_q31.c
A	week2/action-recog-applab/cpp_server/edge-impulse-sdk/CMSIS/DSP/Source/InterpolationFunctions/arm_linear_interp_q7.c
A	week2/action-recog-applab/cpp_server/edge-impulse-sdk/CMSIS/DSP/Source/InterpolationFunctions/arm_spline_interp_f32.c
A	week2/action-recog-applab/cpp_server/edge-impulse-sdk/CMSIS/DSP/Source/InterpolationFunctions/arm_spline_interp_init_f32.c
A	week2/action-recog-applab/cpp_server/edge-impulse-sdk/CMSIS/DSP/Source/MatrixFunctions/arm_householder_f16.c
A	week2/action-recog-applab/cpp_server/edge-impulse-sdk/CMSIS/DSP/Source/MatrixFunctions/arm_householder_f32.c
A	week2/action-recog-applab/cpp_server/edge-impulse-sdk/CMSIS/DSP/Source/MatrixFunctions/arm_householder_f64.c
A	week2/action-recog-applab/cpp_server/edge-impulse-sdk/CMSIS/DSP/Source/MatrixFunctions/arm_mat_add_f16.c
A	week2/action-recog-applab/cpp_server/edge-impulse-sdk/CMSIS/DSP/Source/MatrixFunctions/arm_mat_add_f32.c
A	week2/action-recog-applab/cpp_server/edge-impulse-sdk/CMSIS/DSP/Source/MatrixFunctions/arm_mat_add_q15.c
A	week2/action-recog-applab/cpp_server/edge-impulse-sdk/CMSIS/DSP/Source/MatrixFunctions/arm_mat_add_q31.c
A	week2/action-recog-applab/cpp_server/edge-impulse-sdk/CMSIS/DSP/Source/MatrixFunctions/arm_mat_cholesky_f16.c
A	week2/action-recog-applab/cpp_server/edge-impulse-sdk/CMSIS/DSP/Source/MatrixFunctions/arm_mat_cholesky_f32.c
A	week2/action-recog-applab/cpp_server/edge-impulse-sdk/CMSIS/DSP/Source/MatrixFunctions/arm_mat_cholesky_f64.c
A	week2/action-recog-applab/cpp_server/edge-impulse-sdk/CMSIS/DSP/Source/MatrixFunctions/arm_mat_cmplx_mult_f16.c
A	week2/action-recog-applab/cpp_server/edge-impulse-sdk/CMSIS/DSP/Source/MatrixFunctions/arm_mat_cmplx_mult_f32.c
A	week2/action-recog-applab/cpp_server/edge-impulse-sdk/CMSIS/DSP/Source/MatrixFunctions/arm_mat_cmplx_mult_q15.c
A	week2/action-recog-applab/cpp_server/edge-impulse-sdk/CMSIS/DSP/Source/MatrixFunctions/arm_mat_cmplx_mult_q31.c
A	week2/action-recog-applab/cpp_server/edge-impulse-sdk/CMSIS/DSP/Source/MatrixFunctions/arm_mat_cmplx_trans_f16.c
A	week2/action-recog-applab/cpp_server/edge-impulse-sdk/CMSIS/DSP/Source/MatrixFunctions/arm_mat_cmplx_trans_f32.c
A	week2/action-recog-applab/cpp_server/edge-impulse-sdk/CMSIS/DSP/Source/MatrixFunctions/arm_mat_cmplx_trans_q15.c
A	week2/action-recog-applab/cpp_server/edge-impulse-sdk/CMSIS/DSP/Source/MatrixFunctions/arm_mat_cmplx_trans_q31.c
A	week2/action-recog-applab/cpp_server/edge-impulse-sdk/CMSIS/DSP/Source/MatrixFunctions/arm_mat_init_f16.c
A	week2/action-recog-applab/cpp_server/edge-impulse-sdk/CMSIS/DSP/Source/MatrixFunctions/arm_mat_init_f32.c
A	week2/action-recog-applab/cpp_server/edge-impulse-sdk/CMSIS/DSP/Source/MatrixFunctions/arm_mat_init_q15.c
A	week2/action-recog-applab/cpp_server/edge-impulse-sdk/CMSIS/DSP/Source/MatrixFunctions/arm_mat_init_q31.c
A	week2/action-recog-applab/cpp_server/edge-impulse-sdk/CMSIS/DSP/Source/MatrixFunctions/arm_mat_inverse_f16.c
A	week2/action-recog-applab/cpp_server/edge-impulse-sdk/CMSIS/DSP/Source/MatrixFunctions/arm_mat_inverse_f32.c
A	week2/action-recog-applab/cpp_server/edge-impulse-sdk/CMSIS/DSP/Source/MatrixFunctions/arm_mat_inverse_f64.c
A	week2/action-recog-applab/cpp_server/edge-impulse-sdk/CMSIS/DSP/Source/MatrixFunctions/arm_mat_ldlt_f32.c
A	week2/action-recog-applab/cpp_server/edge-impulse-sdk/CMSIS/DSP/Source/MatrixFunctions/arm_mat_ldlt_f64.c
A	week2/action-recog-applab/cpp_server/edge-impulse-sdk/CMSIS/DSP/Source/MatrixFunctions/arm_mat_mult_f16.c
A	week2/action-recog-applab/cpp_server/edge-impulse-sdk/CMSIS/DSP/Source/MatrixFunctions/arm_mat_mult_f32.c
A	week2/action-recog-applab/cpp_server/edge-impulse-sdk/CMSIS/DSP/Source/MatrixFunctions/arm_mat_mult_f64.c
A	week2/action-recog-applab/cpp_server/edge-impulse-sdk/CMSIS/DSP/Source/MatrixFunctions/arm_mat_mult_fast_q15.c
A	week2/action-recog-applab/cpp_server/edge-impulse-sdk/CMSIS/DSP/Source/MatrixFunctions/arm_mat_mult_fast_q31.c
A	week2/action-recog-applab/cpp_server/edge-impulse-sdk/CMSIS/DSP/Source/MatrixFunctions/arm_mat_mult_opt_q31.c
A	week2/action-recog-applab/cpp_server/edge-impulse-sdk/CMSIS/DSP/Source/MatrixFunctions/arm_mat_mult_q15.c
A	week2/action-recog-applab/cpp_server/edge-impulse-sdk/CMSIS/DSP/Source/MatrixFunctions/arm_mat_mult_q31.c
A	week2/action-recog-applab/cpp_server/edge-impulse-sdk/CMSIS/DSP/Source/MatrixFunctions/arm_mat_mult_q7.c
A	week2/action-recog-applab/cpp_server/edge-impulse-sdk/CMSIS/DSP/Source/MatrixFunctions/arm_mat_qr_f16.c
A	week2/action-recog-applab/cpp_server/edge-impulse-sdk/CMSIS/DSP/Source/MatrixFunctions/arm_mat_qr_f32.c
A	week2/action-recog-applab/cpp_server/edge-impulse-sdk/CMSIS/DSP/Source/MatrixFunctions/arm_mat_qr_f64.c
A	week2/action-recog-applab/cpp_server/edge-impulse-sdk/CMSIS/DSP/Source/MatrixFunctions/arm_mat_scale_f16.c
A	week2/action-recog-applab/cpp_server/edge-impulse-sdk/CMSIS/DSP/Source/MatrixFunctions/arm_mat_scale_f32.c
A	week2/action-recog-applab/cpp_server/edge-impulse-sdk/CMSIS/DSP/Source/MatrixFunctions/arm_mat_scale_q15.c
A	week2/action-recog-applab/cpp_server/edge-impulse-sdk/CMSIS/DSP/Source/MatrixFunctions/arm_mat_scale_q31.c
A	week2/action-recog-applab/cpp_server/edge-impulse-sdk/CMSIS/DSP/Source/MatrixFunctions/arm_mat_solve_lower_triangular_f16.c
A	week2/action-recog-applab/cpp_server/edge-impulse-sdk/CMSIS/DSP/Source/MatrixFunctions/arm_mat_solve_lower_triangular_f32.c
A	week2/action-recog-applab/cpp_server/edge-impulse-sdk/CMSIS/DSP/Source/MatrixFunctions/arm_mat_solve_lower_triangular_f64.c
A	week2/action-recog-applab/cpp_server/edge-impulse-sdk/CMSIS/DSP/Source/MatrixFunctions/arm_mat_solve_upper_triangular_f16.c
A	week2/action-recog-applab/cpp_server/edge-impulse-sdk/CMSIS/DSP/Source/MatrixFunctions/arm_mat_solve_upper_triangular_f32.c
A	week2/action-recog-applab/cpp_server/edge-impulse-sdk/CMSIS/DSP/Source/MatrixFunctions/arm_mat_solve_upper_triangular_f64.c
A	week2/action-recog-applab/cpp_server/edge-impulse-sdk/CMSIS/DSP/Source/MatrixFunctions/arm_mat_sub_f16.c
A	week2/action-recog-applab/cpp_server/edge-impulse-sdk/CMSIS/DSP/Source/MatrixFunctions/arm_mat_sub_f32.c
A	week2/action-recog-applab/cpp_server/edge-impulse-sdk/CMSIS/DSP/Source/MatrixFunctions/arm_mat_sub_f64.c
A	week2/action-recog-applab/cpp_server/edge-impulse-sdk/CMSIS/DSP/Source/MatrixFunctions/arm_mat_sub_q15.c
A	week2/action-recog-applab/cpp_server/edge-impulse-sdk/CMSIS/DSP/Source/MatrixFunctions/arm_mat_sub_q31.c
A	week2/action-recog-applab/cpp_server/edge-impulse-sdk/CMSIS/DSP/Source/MatrixFunctions/arm_mat_trans_f16.c
A	week2/action-recog-applab/cpp_server/edge-impulse-sdk/CMSIS/DSP/Source/MatrixFunctions/arm_mat_trans_f32.c
A	week2/action-recog-applab/cpp_server/edge-impulse-sdk/CMSIS/DSP/Source/MatrixFunctions/arm_mat_trans_f64.c
A	week2/action-recog-applab/cpp_server/edge-impulse-sdk/CMSIS/DSP/Source/MatrixFunctions/arm_mat_trans_q15.c
A	week2/action-recog-applab/cpp_server/edge-impulse-sdk/CMSIS/DSP/Source/MatrixFunctions/arm_mat_trans_q31.c
A	week2/action-recog-applab/cpp_server/edge-impulse-sdk/CMSIS/DSP/Source/MatrixFunctions/arm_mat_trans_q7.c
A	week2/action-recog-applab/cpp_server/edge-impulse-sdk/CMSIS/DSP/Source/MatrixFunctions/arm_mat_vec_mult_f16.c
A	week2/action-recog-applab/cpp_server/edge-impulse-sdk/CMSIS/DSP/Source/MatrixFunctions/arm_mat_vec_mult_f32.c
A	week2/action-recog-applab/cpp_server/edge-impulse-sdk/CMSIS/DSP/Source/MatrixFunctions/arm_mat_vec_mult_q15.c
A	week2/action-recog-applab/cpp_server/edge-impulse-sdk/CMSIS/DSP/Source/MatrixFunctions/arm_mat_vec_mult_q31.c
A	week2/action-recog-applab/cpp_server/edge-impulse-sdk/CMSIS/DSP/Source/MatrixFunctions/arm_mat_vec_mult_q7.c
A	week2/action-recog-applab/cpp_server/edge-impulse-sdk/CMSIS/DSP/Source/QuaternionMathFunctions/arm_quaternion2rotation_f32.c
A	week2/action-recog-applab/cpp_server/edge-impulse-sdk/CMSIS/DSP/Source/QuaternionMathFunctions/arm_quaternion_conjugate_f32.c
A	week2/action-recog-applab/cpp_server/edge-impulse-sdk/CMSIS/DSP/Source/QuaternionMathFunctions/arm_quaternion_inverse_f32.c
A	week2/action-recog-applab/cpp_server/edge-impulse-sdk/CMSIS/DSP/Source/QuaternionMathFunctions/arm_quaternion_norm_f32.c
A	week2/action-recog-applab/cpp_server/edge-impulse-sdk/CMSIS/DSP/Source/QuaternionMathFunctions/arm_quaternion_normalize_f32.c
A	week2/action-recog-applab/cpp_server/edge-impulse-sdk/CMSIS/DSP/Source/QuaternionMathFunctions/arm_quaternion_product_f32.c
A	week2/action-recog-applab/cpp_server/edge-impulse-sdk/CMSIS/DSP/Source/QuaternionMathFunctions/arm_quaternion_product_single_f32.c
A	week2/action-recog-applab/cpp_server/edge-impulse-sdk/CMSIS/DSP/Source/QuaternionMathFunctions/arm_rotation2quaternion_f32.c
A	week2/action-recog-applab/cpp_server/edge-impulse-sdk/CMSIS/DSP/Source/SVMFunctions/arm_svm_linear_init_f16.c
A	week2/action-recog-applab/cpp_server/edge-impulse-sdk/CMSIS/DSP/Source/SVMFunctions/arm_svm_linear_init_f32.c
A	week2/action-recog-applab/cpp_server/edge-impulse-sdk/CMSIS/DSP/Source/SVMFunctions/arm_svm_linear_predict_f16.c
A	week2/action-recog-applab/cpp_server/edge-impulse-sdk/CMSIS/DSP/Source/SVMFunctions/arm_svm_linear_predict_f32.c
A	week2/action-recog-applab/cpp_server/edge-impulse-sdk/CMSIS/DSP/Source/SVMFunctions/arm_svm_polynomial_init_f16.c
A	week2/action-recog-applab/cpp_server/edge-impulse-sdk/CMSIS/DSP/Source/SVMFunctions/arm_svm_polynomial_init_f32.c
A	week2/action-recog-applab/cpp_server/edge-impulse-sdk/CMSIS/DSP/Source/SVMFunctions/arm_svm_polynomial_predict_f16.c
A	week2/action-recog-applab/cpp_server/edge-impulse-sdk/CMSIS/DSP/Source/SVMFunctions/arm_svm_polynomial_predict_f32.c
A	week2/action-recog-applab/cpp_server/edge-impulse-sdk/CMSIS/DSP/Source/SVMFunctions/arm_svm_rbf_init_f16.c
A	week2/action-recog-applab/cpp_server/edge-impulse-sdk/CMSIS/DSP/Source/SVMFunctions/arm_svm_rbf_init_f32.c
A	week2/action-recog-applab/cpp_server/edge-impulse-sdk/CMSIS/DSP/Source/SVMFunctions/arm_svm_rbf_predict_f16.c
A	week2/action-recog-applab/cpp_server/edge-impulse-sdk/CMSIS/DSP/Source/SVMFunctions/arm_svm_rbf_predict_f32.c
A	week2/action-recog-applab/cpp_server/edge-impulse-sdk/CMSIS/DSP/Source/SVMFunctions/arm_svm_sigmoid_init_f16.c
A	week2/action-recog-applab/cpp_server/edge-impulse-sdk/CMSIS/DSP/Source/SVMFunctions/arm_svm_sigmoid_init_f32.c
A	week2/action-recog-applab/cpp_server/edge-impulse-sdk/CMSIS/DSP/Source/SVMFunctions/arm_svm_sigmoid_predict_f16.c
A	week2/action-recog-applab/cpp_server/edge-impulse-sdk/CMSIS/DSP/Source/SVMFunctions/arm_svm_sigmoid_predict_f32.c
A	week2/action-recog-applab/cpp_server/edge-impulse-sdk/CMSIS/DSP/Source/StatisticsFunctions/arm_absmax_f16.c
A	week2/action-recog-applab/cpp_server/edge-impulse-sdk/CMSIS/DSP/Source/StatisticsFunctions/arm_absmax_f32.c
A	week2/action-recog-applab/cpp_server/edge-impulse-sdk/CMSIS/DSP/Source/StatisticsFunctions/arm_absmax_f64.c
A	week2/action-recog-applab/cpp_server/edge-impulse-sdk/CMSIS/DSP/Source/StatisticsFunctions/arm_absmax_no_idx_f16.c
A	week2/action-recog-applab/cpp_server/edge-impulse-sdk/CMSIS/DSP/Source/StatisticsFunctions/arm_absmax_no_idx_f32.c
A	week2/action-recog-applab/cpp_server/edge-impulse-sdk/CMSIS/DSP/Source/StatisticsFunctions/arm_absmax_no_idx_f64.c
A	week2/action-recog-applab/cpp_server/edge-impulse-sdk/CMSIS/DSP/Source/StatisticsFunctions/arm_absmax_no_idx_q15.c
A	week2/action-recog-applab/cpp_server/edge-impulse-sdk/CMSIS/DSP/Source/StatisticsFunctions/arm_absmax_no_idx_q31.c
A	week2/action-recog-applab/cpp_server/edge-impulse-sdk/CMSIS/DSP/Source/StatisticsFunctions/arm_absmax_no_idx_q7.c
A	week2/action-recog-applab/cpp_server/edge-impulse-sdk/CMSIS/DSP/Source/StatisticsFunctions/arm_absmax_q15.c
A	week2/action-recog-applab/cpp_server/edge-impulse-sdk/CMSIS/DSP/Source/StatisticsFunctions/arm_absmax_q31.c
A	week2/action-recog-applab/cpp_server/edge-impulse-sdk/CMSIS/DSP/Source/StatisticsFunctions/arm_absmax_q7.c
A	week2/action-recog-applab/cpp_server/edge-impulse-sdk/CMSIS/DSP/Source/StatisticsFunctions/arm_absmin_f16.c
A	week2/action-recog-applab/cpp_server/edge-impulse-sdk/CMSIS/DSP/Source/StatisticsFunctions/arm_absmin_f32.c
A	week2/action-recog-applab/cpp_server/edge-impulse-sdk/CMSIS/DSP/Source/StatisticsFunctions/arm_absmin_f64.c
A	week2/action-recog-applab/cpp_server/edge-impulse-sdk/CMSIS/DSP/Source/StatisticsFunctions/arm_absmin_no_idx_f16.c
A	week2/action-recog-applab/cpp_server/edge-impulse-sdk/CMSIS/DSP/Source/StatisticsFunctions/arm_absmin_no_idx_f32.c
A	week2/action-recog-applab/cpp_server/edge-impulse-sdk/CMSIS/DSP/Source/StatisticsFunctions/arm_absmin_no_idx_f64.c
A	week2/action-recog-applab/cpp_server/edge-impulse-sdk/CMSIS/DSP/Source/StatisticsFunctions/arm_absmin_no_idx_q15.c
A	week2/action-recog-applab/cpp_server/edge-impulse-sdk/CMSIS/DSP/Source/StatisticsFunctions/arm_absmin_no_idx_q31.c
A	week2/action-recog-applab/cpp_server/edge-impulse-sdk/CMSIS/DSP/Source/StatisticsFunctions/arm_absmin_no_idx_q7.c
A	week2/action-recog-applab/cpp_server/edge-impulse-sdk/CMSIS/DSP/Source/StatisticsFunctions/arm_absmin_q15.c
A	week2/action-recog-applab/cpp_server/edge-impulse-sdk/CMSIS/DSP/Source/StatisticsFunctions/arm_absmin_q31.c
A	week2/action-recog-applab/cpp_server/edge-impulse-sdk/CMSIS/DSP/Source/StatisticsFunctions/arm_absmin_q7.c
A	week2/action-recog-applab/cpp_server/edge-impulse-sdk/CMSIS/DSP/Source/StatisticsFunctions/arm_accumulate_f16.c
A	week2/action-recog-applab/cpp_server/edge-impulse-sdk/CMSIS/DSP/Source/StatisticsFunctions/arm_accumulate_f32.c
A	week2/action-recog-applab/cpp_server/edge-impulse-sdk/CMSIS/DSP/Source/StatisticsFunctions/arm_accumulate_f64.c
A	week2/action-recog-applab/cpp_server/edge-impulse-sdk/CMSIS/DSP/Source/StatisticsFunctions/arm_entropy_f16.c
A	week2/action-recog-applab/cpp_server/edge-impulse-sdk/CMSIS/DSP/Source/StatisticsFunctions/arm_entropy_f32.c
A	week2/action-recog-applab/cpp_server/edge-impulse-sdk/CMSIS/DSP/Source/StatisticsFunctions/arm_entropy_f64.c
A	week2/action-recog-applab/cpp_server/edge-impulse-sdk/CMSIS/DSP/Source/StatisticsFunctions/arm_kullback_leibler_f16.c
A	week2/action-recog-applab/cpp_server/edge-impulse-sdk/CMSIS/DSP/Source/StatisticsFunctions/arm_kullback_leibler_f32.c
A	week2/action-recog-applab/cpp_server/edge-impulse-sdk/CMSIS/DSP/Source/StatisticsFunctions/arm_kullback_leibler_f64.c
A	week2/action-recog-applab/cpp_server/edge-impulse-sdk/CMSIS/DSP/Source/StatisticsFunctions/arm_logsumexp_dot_prod_f16.c
A	week2/action-recog-applab/cpp_server/edge-impulse-sdk/CMSIS/DSP/Source/StatisticsFunctions/arm_logsumexp_dot_prod_f32.c
A	week2/action-recog-applab/cpp_server/edge-impulse-sdk/CMSIS/DSP/Source/StatisticsFunctions/arm_logsumexp_f16.c
A	week2/action-recog-applab/cpp_server/edge-impulse-sdk/CMSIS/DSP/Source/StatisticsFunctions/arm_logsumexp_f32.c
A	week2/action-recog-applab/cpp_server/edge-impulse-sdk/CMSIS/DSP/Source/StatisticsFunctions/arm_max_f16.c
A	week2/action-recog-applab/cpp_server/edge-impulse-sdk/CMSIS/DSP/Source/StatisticsFunctions/arm_max_f32.c
A	week2/action-recog-applab/cpp_server/edge-impulse-sdk/CMSIS/DSP/Source/StatisticsFunctions/arm_max_f64.c
A	week2/action-recog-applab/cpp_server/edge-impulse-sdk/CMSIS/DSP/Source/StatisticsFunctions/arm_max_no_idx_f16.c
A	week2/action-recog-applab/cpp_server/edge-impulse-sdk/CMSIS/DSP/Source/StatisticsFunctions/arm_max_no_idx_f32.c
A	week2/action-recog-applab/cpp_server/edge-impulse-sdk/CMSIS/DSP/Source/StatisticsFunctions/arm_max_no_idx_f64.c
A	week2/action-recog-applab/cpp_server/edge-impulse-sdk/CMSIS/DSP/Source/StatisticsFunctions/arm_max_no_idx_q15.c
A	week2/action-recog-applab/cpp_server/edge-impulse-sdk/CMSIS/DSP/Source/StatisticsFunctions/arm_max_no_idx_q31.c
A	week2/action-recog-applab/cpp_server/edge-impulse-sdk/CMSIS/DSP/Source/StatisticsFunctions/arm_max_no_idx_q7.c
A	week2/action-recog-applab/cpp_server/edge-impulse-sdk/CMSIS/DSP/Source/StatisticsFunctions/arm_max_q15.c
A	week2/action-recog-applab/cpp_server/edge-impulse-sdk/CMSIS/DSP/Source/StatisticsFunctions/arm_max_q31.c
A	week2/action-recog-applab/cpp_server/edge-impulse-sdk/CMSIS/DSP/Source/StatisticsFunctions/arm_max_q7.c
A	week2/action-recog-applab/cpp_server/edge-impulse-sdk/CMSIS/DSP/Source/StatisticsFunctions/arm_mean_f16.c
A	week2/action-recog-applab/cpp_server/edge-impulse-sdk/CMSIS/DSP/Source/StatisticsFunctions/arm_mean_f32.c
A	week2/action-recog-applab/cpp_server/edge-impulse-sdk/CMSIS/DSP/Source/StatisticsFunctions/arm_mean_f64.c
A	week2/action-recog-applab/cpp_server/edge-impulse-sdk/CMSIS/DSP/Source/StatisticsFunctions/arm_mean_q15.c
A	week2/action-recog-applab/cpp_server/edge-impulse-sdk/CMSIS/DSP/Source/StatisticsFunctions/arm_mean_q31.c
A	week2/action-recog-applab/cpp_server/edge-impulse-sdk/CMSIS/DSP/Source/StatisticsFunctions/arm_mean_q7.c
A	week2/action-recog-applab/cpp_server/edge-impulse-sdk/CMSIS/DSP/Source/StatisticsFunctions/arm_min_f16.c
A	week2/action-recog-applab/cpp_server/edge-impulse-sdk/CMSIS/DSP/Source/StatisticsFunctions/arm_min_f32.c
A	week2/action-recog-applab/cpp_server/edge-impulse-sdk/CMSIS/DSP/Source/StatisticsFunctions/arm_min_f64.c
A	week2/action-recog-applab/cpp_server/edge-impulse-sdk/CMSIS/DSP/Source/StatisticsFunctions/arm_min_no_idx_f16.c
A	week2/action-recog-applab/cpp_server/edge-impulse-sdk/CMSIS/DSP/Source/StatisticsFunctions/arm_min_no_idx_f32.c
A	week2/action-recog-applab/cpp_server/edge-impulse-sdk/CMSIS/DSP/Source/StatisticsFunctions/arm_min_no_idx_f64.c
A	week2/action-recog-applab/cpp_server/edge-impulse-sdk/CMSIS/DSP/Source/StatisticsFunctions/arm_min_no_idx_q15.c
A	week2/action-recog-applab/cpp_server/edge-impulse-sdk/CMSIS/DSP/Source/StatisticsFunctions/arm_min_no_idx_q31.c
A	week2/action-recog-applab/cpp_server/edge-impulse-sdk/CMSIS/DSP/Source/StatisticsFunctions/arm_min_no_idx_q7.c
A	week2/action-recog-applab/cpp_server/edge-impulse-sdk/CMSIS/DSP/Source/StatisticsFunctions/arm_min_q15.c
A	week2/action-recog-applab/cpp_server/edge-impulse-sdk/CMSIS/DSP/Source/StatisticsFunctions/arm_min_q31.c
A	week2/action-recog-applab/cpp_server/edge-impulse-sdk/CMSIS/DSP/Source/StatisticsFunctions/arm_min_q7.c
A	week2/action-recog-applab/cpp_server/edge-impulse-sdk/CMSIS/DSP/Source/StatisticsFunctions/arm_mse_f16.c
A	week2/action-recog-applab/cpp_server/edge-impulse-sdk/CMSIS/DSP/Source/StatisticsFunctions/arm_mse_f32.c
A	week2/action-recog-applab/cpp_server/edge-impulse-sdk/CMSIS/DSP/Source/StatisticsFunctions/arm_mse_f64.c
A	week2/action-recog-applab/cpp_server/edge-impulse-sdk/CMSIS/DSP/Source/StatisticsFunctions/arm_mse_q15.c
A	week2/action-recog-applab/cpp_server/edge-impulse-sdk/CMSIS/DSP/Source/StatisticsFunctions/arm_mse_q31.c
A	week2/action-recog-applab/cpp_server/edge-impulse-sdk/CMSIS/DSP/Source/StatisticsFunctions/arm_mse_q7.c
A	week2/action-recog-applab/cpp_server/edge-impulse-sdk/CMSIS/DSP/Source/StatisticsFunctions/arm_power_f16.c
A	week2/action-recog-applab/cpp_server/edge-impulse-sdk/CMSIS/DSP/Source/StatisticsFunctions/arm_power_f32.c
A	week2/action-recog-applab/cpp_server/edge-impulse-sdk/CMSIS/DSP/Source/StatisticsFunctions/arm_power_f64.c
A	week2/action-recog-applab/cpp_server/edge-impulse-sdk/CMSIS/DSP/Source/StatisticsFunctions/arm_power_q15.c
A	week2/action-recog-applab/cpp_server/edge-impulse-sdk/CMSIS/DSP/Source/StatisticsFunctions/arm_power_q31.c
A	week2/action-recog-applab/cpp_server/edge-impulse-sdk/CMSIS/DSP/Source/StatisticsFunctions/arm_power_q7.c
A	week2/action-recog-applab/cpp_server/edge-impulse-sdk/CMSIS/DSP/Source/StatisticsFunctions/arm_rms_f16.c
A	week2/action-recog-applab/cpp_server/edge-impulse-sdk/CMSIS/DSP/Source/StatisticsFunctions/arm_rms_f32.c
A	week2/action-recog-applab/cpp_server/edge-impulse-sdk/CMSIS/DSP/Source/StatisticsFunctions/arm_rms_q15.c
A	week2/action-recog-applab/cpp_server/edge-impulse-sdk/CMSIS/DSP/Source/StatisticsFunctions/arm_rms_q31.c
A	week2/action-recog-applab/cpp_server/edge-impulse-sdk/CMSIS/DSP/Source/StatisticsFunctions/arm_std_f16.c
A	week2/action-recog-applab/cpp_server/edge-impulse-sdk/CMSIS/DSP/Source/StatisticsFunctions/arm_std_f32.c
A	week2/action-recog-applab/cpp_server/edge-impulse-sdk/CMSIS/DSP/Source/StatisticsFunctions/arm_std_f64.c
A	week2/action-recog-applab/cpp_server/edge-impulse-sdk/CMSIS/DSP/Source/StatisticsFunctions/arm_std_q15.c
A	week2/action-recog-applab/cpp_server/edge-impulse-sdk/CMSIS/DSP/Source/StatisticsFunctions/arm_std_q31.c
A	week2/action-recog-applab/cpp_server/edge-impulse-sdk/CMSIS/DSP/Source/StatisticsFunctions/arm_var_f16.c
A	week2/action-recog-applab/cpp_server/edge-impulse-sdk/CMSIS/DSP/Source/StatisticsFunctions/arm_var_f32.c
A	week2/action-recog-applab/cpp_server/edge-impulse-sdk/CMSIS/DSP/Source/StatisticsFunctions/arm_var_f64.c
A	week2/action-recog-applab/cpp_server/edge-impulse-sdk/CMSIS/DSP/Source/StatisticsFunctions/arm_var_q15.c
A	week2/action-recog-applab/cpp_server/edge-impulse-sdk/CMSIS/DSP/Source/StatisticsFunctions/arm_var_q31.c
A	week2/action-recog-applab/cpp_server/edge-impulse-sdk/CMSIS/DSP/Source/SupportFunctions/arm_barycenter_f16.c
A	week2/action-recog-applab/cpp_server/edge-impulse-sdk/CMSIS/DSP/Source/SupportFunctions/arm_barycenter_f32.c
A	week2/action-recog-applab/cpp_server/edge-impulse-sdk/CMSIS/DSP/Source/SupportFunctions/arm_bitonic_sort_f32.c
A	week2/action-recog-applab/cpp_server/edge-impulse-sdk/CMSIS/DSP/Source/SupportFunctions/arm_bubble_sort_f32.c
A	week2/action-recog-applab/cpp_server/edge-impulse-sdk/CMSIS/DSP/Source/SupportFunctions/arm_copy_f16.c
A	week2/action-recog-applab/cpp_server/edge-impulse-sdk/CMSIS/DSP/Source/SupportFunctions/arm_copy_f32.c
A	week2/action-recog-applab/cpp_server/edge-impulse-sdk/CMSIS/DSP/Source/SupportFunctions/arm_copy_f64.c
A	week2/action-recog-applab/cpp_server/edge-impulse-sdk/CMSIS/DSP/Source/SupportFunctions/arm_copy_q15.c
A	week2/action-recog-applab/cpp_server/edge-impulse-sdk/CMSIS/DSP/Source/SupportFunctions/arm_copy_q31.c
A	week2/action-recog-applab/cpp_server/edge-impulse-sdk/CMSIS/DSP/Source/SupportFunctions/arm_copy_q7.c
A	week2/action-recog-applab/cpp_server/edge-impulse-sdk/CMSIS/DSP/Source/SupportFunctions/arm_f16_to_float.c
A	week2/action-recog-applab/cpp_server/edge-impulse-sdk/CMSIS/DSP/Source/SupportFunctions/arm_f16_to_q15.c
A	week2/action-recog-applab/cpp_server/edge-impulse-sdk/CMSIS/DSP/Source/SupportFunctions/arm_fill_f16.c
A	week2/action-recog-applab/cpp_server/edge-impulse-sdk/CMSIS/DSP/Source/SupportFunctions/arm_fill_f32.c
A	week2/action-recog-applab/cpp_server/edge-impulse-sdk/CMSIS/DSP/Source/SupportFunctions/arm_fill_f64.c
A	week2/action-recog-applab/cpp_server/edge-impulse-sdk/CMSIS/DSP/Source/SupportFunctions/arm_fill_q15.c
A	week2/action-recog-applab/cpp_server/edge-impulse-sdk/CMSIS/DSP/Source/SupportFunctions/arm_fill_q31.c
A	week2/action-recog-applab/cpp_server/edge-impulse-sdk/CMSIS/DSP/Source/SupportFunctions/arm_fill_q7.c
A	week2/action-recog-applab/cpp_server/edge-impulse-sdk/CMSIS/DSP/Source/SupportFunctions/arm_float_to_f16.c
A	week2/action-recog-applab/cpp_server/edge-impulse-sdk/CMSIS/DSP/Source/SupportFunctions/arm_float_to_q15.c
A	week2/action-recog-applab/cpp_server/edge-impulse-sdk/CMSIS/DSP/Source/SupportFunctions/arm_float_to_q31.c
A	week2/action-recog-applab/cpp_server/edge-impulse-sdk/CMSIS/DSP/Source/SupportFunctions/arm_float_to_q7.c
A	week2/action-recog-applab/cpp_server/edge-impulse-sdk/CMSIS/DSP/Source/SupportFunctions/arm_heap_sort_f32.c
A	week2/action-recog-applab/cpp_server/edge-impulse-sdk/CMSIS/DSP/Source/SupportFunctions/arm_insertion_sort_f32.c
A	week2/action-recog-applab/cpp_server/edge-impulse-sdk/CMSIS/DSP/Source/SupportFunctions/arm_merge_sort_f32.c
A	week2/action-recog-applab/cpp_server/edge-impulse-sdk/CMSIS/DSP/Source/SupportFunctions/arm_merge_sort_init_f32.c
A	week2/action-recog-applab/cpp_server/edge-impulse-sdk/CMSIS/DSP/Source/SupportFunctions/arm_q15_to_f16.c
A	week2/action-recog-applab/cpp_server/edge-impulse-sdk/CMSIS/DSP/Source/SupportFunctions/arm_q15_to_float.c
A	week2/action-recog-applab/cpp_server/edge-impulse-sdk/CMSIS/DSP/Source/SupportFunctions/arm_q15_to_q31.c
A	week2/action-recog-applab/cpp_server/edge-impulse-sdk/CMSIS/DSP/Source/SupportFunctions/arm_q15_to_q7.c
A	week2/action-recog-applab/cpp_server/edge-impulse-sdk/CMSIS/DSP/Source/SupportFunctions/arm_q31_to_float.c
A	week2/action-recog-applab/cpp_server/edge-impulse-sdk/CMSIS/DSP/Source/SupportFunctions/arm_q31_to_q15.c
A	week2/action-recog-applab/cpp_server/edge-impulse-sdk/CMSIS/DSP/Source/SupportFunctions/arm_q31_to_q7.c
A	week2/action-recog-applab/cpp_server/edge-impulse-sdk/CMSIS/DSP/Source/SupportFunctions/arm_q7_to_float.c
A	week2/action-recog-applab/cpp_server/edge-impulse-sdk/CMSIS/DSP/Source/SupportFunctions/arm_q7_to_q15.c
A	week2/action-recog-applab/cpp_server/edge-impulse-sdk/CMSIS/DSP/Source/SupportFunctions/arm_q7_to_q31.c
A	week2/action-recog-applab/cpp_server/edge-impulse-sdk/CMSIS/DSP/Source/SupportFunctions/arm_quick_sort_f32.c
A	week2/action-recog-applab/cpp_server/edge-impulse-sdk/CMSIS/DSP/Source/SupportFunctions/arm_selection_sort_f32.c
A	week2/action-recog-applab/cpp_server/edge-impulse-sdk/CMSIS/DSP/Source/SupportFunctions/arm_sort_f32.c
A	week2/action-recog-applab/cpp_server/edge-impulse-sdk/CMSIS/DSP/Source/SupportFunctions/arm_sort_init_f32.c
A	week2/action-recog-applab/cpp_server/edge-impulse-sdk/CMSIS/DSP/Source/SupportFunctions/arm_weighted_sum_f16.c
A	week2/action-recog-applab/cpp_server/edge-impulse-sdk/CMSIS/DSP/Source/SupportFunctions/arm_weighted_sum_f32.c
A	week2/action-recog-applab/cpp_server/edge-impulse-sdk/CMSIS/DSP/Source/TransformFunctions/arm_bitreversal.c
A	week2/action-recog-applab/cpp_server/edge-impulse-sdk/CMSIS/DSP/Source/TransformFunctions/arm_bitreversal2.c
A	week2/action-recog-applab/cpp_server/edge-impulse-sdk/CMSIS/DSP/Source/TransformFunctions/arm_bitreversal_f16.c
A	week2/action-recog-applab/cpp_server/edge-impulse-sdk/CMSIS/DSP/Source/TransformFunctions/arm_cfft_f16.c
A	week2/action-recog-applab/cpp_server/edge-impulse-sdk/CMSIS/DSP/Source/TransformFunctions/arm_cfft_f32.c
A	week2/action-recog-applab/cpp_server/edge-impulse-sdk/CMSIS/DSP/Source/TransformFunctions/arm_cfft_f64.c
A	week2/action-recog-applab/cpp_server/edge-impulse-sdk/CMSIS/DSP/Source/TransformFunctions/arm_cfft_init_f16.c
A	week2/action-recog-applab/cpp_server/edge-impulse-sdk/CMSIS/DSP/Source/TransformFunctions/arm_cfft_init_f32.c
A	week2/action-recog-applab/cpp_server/edge-impulse-sdk/CMSIS/DSP/Source/TransformFunctions/arm_cfft_init_f64.c
A	week2/action-recog-applab/cpp_server/edge-impulse-sdk/CMSIS/DSP/Source/TransformFunctions/arm_cfft_init_q15.c
A	week2/action-recog-applab/cpp_server/edge-impulse-sdk/CMSIS/DSP/Source/TransformFunctions/arm_cfft_init_q31.c
A	week2/action-recog-applab/cpp_server/edge-impulse-sdk/CMSIS/DSP/Source/TransformFunctions/arm_cfft_q15.c
A	week2/action-recog-applab/cpp_server/edge-impulse-sdk/CMSIS/DSP/Source/TransformFunctions/arm_cfft_q31.c
A	week2/action-recog-applab/cpp_server/edge-impulse-sdk/CMSIS/DSP/Source/TransformFunctions/arm_cfft_radix2_f16.c
A	week2/action-recog-applab/cpp_server/edge-impulse-sdk/CMSIS/DSP/Source/TransformFunctions/arm_cfft_radix2_f32.c
A	week2/action-recog-applab/cpp_server/edge-impulse-sdk/CMSIS/DSP/Source/TransformFunctions/arm_cfft_radix2_init_f16.c
A	week2/action-recog-applab/cpp_server/edge-impulse-sdk/CMSIS/DSP/Source/TransformFunctions/arm_cfft_radix2_init_f32.c
A	week2/action-recog-applab/cpp_server/edge-impulse-sdk/CMSIS/DSP/Source/TransformFunctions/arm_cfft_radix2_init_q15.c
A	week2/action-recog-applab/cpp_server/edge-impulse-sdk/CMSIS/DSP/Source/TransformFunctions/arm_cfft_radix2_init_q31.c
A	week2/action-recog-applab/cpp_server/edge-impulse-sdk/CMSIS/DSP/Source/TransformFunctions/arm_cfft_radix2_q15.c
A	week2/action-recog-applab/cpp_server/edge-impulse-sdk/CMSIS/DSP/Source/TransformFunctions/arm_cfft_radix2_q31.c
A	week2/action-recog-applab/cpp_server/edge-impulse-sdk/CMSIS/DSP/Source/TransformFunctions/arm_cfft_radix4_f16.c
A	week2/action-recog-applab/cpp_server/edge-impulse-sdk/CMSIS/DSP/Source/TransformFunctions/arm_cfft_radix4_f32.c
A	week2/action-recog-applab/cpp_server/edge-impulse-sdk/CMSIS/DSP/Source/TransformFunctions/arm_cfft_radix4_init_f16.c
A	week2/action-recog-applab/cpp_server/edge-impulse-sdk/CMSIS/DSP/Source/TransformFunctions/arm_cfft_radix4_init_f32.c
A	week2/action-recog-applab/cpp_server/edge-impulse-sdk/CMSIS/DSP/Source/TransformFunctions/arm_cfft_radix4_init_q15.c
A	week2/action-recog-applab/cpp_server/edge-impulse-sdk/CMSIS/DSP/Source/TransformFunctions/arm_cfft_radix4_init_q31.c
A	week2/action-recog-applab/cpp_server/edge-impulse-sdk/CMSIS/DSP/Source/TransformFunctions/arm_cfft_radix4_q15.c
A	week2/action-recog-applab/cpp_server/edge-impulse-sdk/CMSIS/DSP/Source/TransformFunctions/arm_cfft_radix4_q31.c
A	week2/action-recog-applab/cpp_server/edge-impulse-sdk/CMSIS/DSP/Source/TransformFunctions/arm_cfft_radix8_f16.c
A	week2/action-recog-applab/cpp_server/edge-impulse-sdk/CMSIS/DSP/Source/TransformFunctions/arm_cfft_radix8_f32.c
A	week2/action-recog-applab/cpp_server/edge-impulse-sdk/CMSIS/DSP/Source/TransformFunctions/arm_dct4_f32.c
A	week2/action-recog-applab/cpp_server/edge-impulse-sdk/CMSIS/DSP/Source/TransformFunctions/arm_dct4_init_f32.c
A	week2/action-recog-applab/cpp_server/edge-impulse-sdk/CMSIS/DSP/Source/TransformFunctions/arm_dct4_init_q15.c
A	week2/action-recog-applab/cpp_server/edge-impulse-sdk/CMSIS/DSP/Source/TransformFunctions/arm_dct4_init_q31.c
A	week2/action-recog-applab/cpp_server/edge-impulse-sdk/CMSIS/DSP/Source/TransformFunctions/arm_dct4_q15.c
A	week2/action-recog-applab/cpp_server/edge-impulse-sdk/CMSIS/DSP/Source/TransformFunctions/arm_dct4_q31.c
A	week2/action-recog-applab/cpp_server/edge-impulse-sdk/CMSIS/DSP/Source/TransformFunctions/arm_mfcc_f16.c
A	week2/action-recog-applab/cpp_server/edge-impulse-sdk/CMSIS/DSP/Source/TransformFunctions/arm_mfcc_f32.c
A	week2/action-recog-applab/cpp_server/edge-impulse-sdk/CMSIS/DSP/Source/TransformFunctions/arm_mfcc_init_f16.c
A	week2/action-recog-applab/cpp_server/edge-impulse-sdk/CMSIS/DSP/Source/TransformFunctions/arm_mfcc_init_f32.c
A	week2/action-recog-applab/cpp_server/edge-impulse-sdk/CMSIS/DSP/Source/TransformFunctions/arm_mfcc_init_q15.c
A	week2/action-recog-applab/cpp_server/edge-impulse-sdk/CMSIS/DSP/Source/TransformFunctions/arm_mfcc_init_q31.c
A	week2/action-recog-applab/cpp_server/edge-impulse-sdk/CMSIS/DSP/Source/TransformFunctions/arm_mfcc_q15.c
A	week2/action-recog-applab/cpp_server/edge-impulse-sdk/CMSIS/DSP/Source/TransformFunctions/arm_mfcc_q31.c
A	week2/action-recog-applab/cpp_server/edge-impulse-sdk/CMSIS/DSP/Source/TransformFunctions/arm_rfft_f32.c
A	week2/action-recog-applab/cpp_server/edge-impulse-sdk/CMSIS/DSP/Source/TransformFunctions/arm_rfft_fast_f16.c
A	week2/action-recog-applab/cpp_server/edge-impulse-sdk/CMSIS/DSP/Source/TransformFunctions/arm_rfft_fast_f32.c
A	week2/action-recog-applab/cpp_server/edge-impulse-sdk/CMSIS/DSP/Source/TransformFunctions/arm_rfft_fast_f64.c
A	week2/action-recog-applab/cpp_server/edge-impulse-sdk/CMSIS/DSP/Source/TransformFunctions/arm_rfft_fast_init_f16.c
A	week2/action-recog-applab/cpp_server/edge-impulse-sdk/CMSIS/DSP/Source/TransformFunctions/arm_rfft_fast_init_f32.c
A	week2/action-recog-applab/cpp_server/edge-impulse-sdk/CMSIS/DSP/Source/TransformFunctions/arm_rfft_fast_init_f64.c
A	week2/action-recog-applab/cpp_server/edge-impulse-sdk/CMSIS/DSP/Source/TransformFunctions/arm_rfft_init_f32.c
A	week2/action-recog-applab/cpp_server/edge-impulse-sdk/CMSIS/DSP/Source/TransformFunctions/arm_rfft_init_q15.c
A	week2/action-recog-applab/cpp_server/edge-impulse-sdk/CMSIS/DSP/Source/TransformFunctions/arm_rfft_init_q31.c
A	week2/action-recog-applab/cpp_server/edge-impulse-sdk/CMSIS/DSP/Source/TransformFunctions/arm_rfft_q15.c
A	week2/action-recog-applab/cpp_server/edge-impulse-sdk/CMSIS/DSP/Source/TransformFunctions/arm_rfft_q31.c
A	week2/action-recog-applab/cpp_server/edge-impulse-sdk/CMSIS/NN/Include/arm_nn_math_types.h
A	week2/action-recog-applab/cpp_server/edge-impulse-sdk/CMSIS/NN/Include/arm_nn_tables.h
A	week2/action-recog-applab/cpp_server/edge-impulse-sdk/CMSIS/NN/Include/arm_nn_types.h
A	week2/action-recog-applab/cpp_server/edge-impulse-sdk/CMSIS/NN/Include/arm_nnfunctions.h
A	week2/action-recog-applab/cpp_server/edge-impulse-sdk/CMSIS/NN/Include/arm_nnsupportfunctions.h
A	week2/action-recog-applab/cpp_server/edge-impulse-sdk/CMSIS/NN/Source/ActivationFunctions/arm_nn_activations_q15.c
A	week2/action-recog-applab/cpp_server/edge-impulse-sdk/CMSIS/NN/Source/ActivationFunctions/arm_nn_activations_q7.c
A	week2/action-recog-applab/cpp_server/edge-impulse-sdk/CMSIS/NN/Source/ActivationFunctions/arm_relu6_s8.c
A	week2/action-recog-applab/cpp_server/edge-impulse-sdk/CMSIS/NN/Source/ActivationFunctions/arm_relu_q15.c
A	week2/action-recog-applab/cpp_server/edge-impulse-sdk/CMSIS/NN/Source/ActivationFunctions/arm_relu_q7.c
A	week2/action-recog-applab/cpp_server/edge-impulse-sdk/CMSIS/NN/Source/BasicMathFunctions/arm_elementwise_add_s16.c
A	week2/action-recog-applab/cpp_server/edge-impulse-sdk/CMSIS/NN/Source/BasicMathFunctions/arm_elementwise_add_s8.c
A	week2/action-recog-applab/cpp_server/edge-impulse-sdk/CMSIS/NN/Source/BasicMathFunctions/arm_elementwise_mul_s16.c
A	week2/action-recog-applab/cpp_server/edge-impulse-sdk/CMSIS/NN/Source/BasicMathFunctions/arm_elementwise_mul_s8.c
A	week2/action-recog-applab/cpp_server/edge-impulse-sdk/CMSIS/NN/Source/ConcatenationFunctions/arm_concatenation_s8_w.c
A	week2/action-recog-applab/cpp_server/edge-impulse-sdk/CMSIS/NN/Source/ConcatenationFunctions/arm_concatenation_s8_x.c
A	week2/action-recog-applab/cpp_server/edge-impulse-sdk/CMSIS/NN/Source/ConcatenationFunctions/arm_concatenation_s8_y.c
A	week2/action-recog-applab/cpp_server/edge-impulse-sdk/CMSIS/NN/Source/ConcatenationFunctions/arm_concatenation_s8_z.c
A	week2/action-recog-applab/cpp_server/edge-impulse-sdk/CMSIS/NN/Source/ConvolutionFunctions/arm_convolve_1_x_n_s8.c
A	week2/action-recog-applab/cpp_server/edge-impulse-sdk/CMSIS/NN/Source/ConvolutionFunctions/arm_convolve_1x1_HWC_q7_fast_nonsquare.c
A	week2/action-recog-applab/cpp_server/edge-impulse-sdk/CMSIS/NN/Source/ConvolutionFunctions/arm_convolve_1x1_s8_fast.c
A	week2/action-recog-applab/cpp_server/edge-impulse-sdk/CMSIS/NN/Source/ConvolutionFunctions/arm_convolve_HWC_q15_basic.c
A	week2/action-recog-applab/cpp_server/edge-impulse-sdk/CMSIS/NN/Source/ConvolutionFunctions/arm_convolve_HWC_q15_fast.c
A	week2/action-recog-applab/cpp_server/edge-impulse-sdk/CMSIS/NN/Source/ConvolutionFunctions/arm_convolve_HWC_q15_fast_nonsquare.c
A	week2/action-recog-applab/cpp_server/edge-impulse-sdk/CMSIS/NN/Source/ConvolutionFunctions/arm_convolve_HWC_q7_RGB.c
A	week2/action-recog-applab/cpp_server/edge-impulse-sdk/CMSIS/NN/Source/ConvolutionFunctions/arm_convolve_HWC_q7_basic.c
A	week2/action-recog-applab/cpp_server/edge-impulse-sdk/CMSIS/NN/Source/ConvolutionFunctions/arm_convolve_HWC_q7_basic_nonsquare.c
A	week2/action-recog-applab/cpp_server/edge-impulse-sdk/CMSIS/NN/Source/ConvolutionFunctions/arm_convolve_HWC_q7_fast.c
A	week2/action-recog-applab/cpp_server/edge-impulse-sdk/CMSIS/NN/Source/ConvolutionFunctions/arm_convolve_HWC_q7_fast_nonsquare.c
A	week2/action-recog-applab/cpp_server/edge-impulse-sdk/CMSIS/NN/Source/ConvolutionFunctions/arm_convolve_fast_s16.c
A	week2/action-recog-applab/cpp_server/edge-impulse-sdk/CMSIS/NN/Source/ConvolutionFunctions/arm_convolve_s16.c
A	week2/action-recog-applab/cpp_server/edge-impulse-sdk/CMSIS/NN/Source/ConvolutionFunctions/arm_convolve_s8.c
A	week2/action-recog-applab/cpp_server/edge-impulse-sdk/CMSIS/NN/Source/ConvolutionFunctions/arm_convolve_wrapper_s16.c
A	week2/action-recog-applab/cpp_server/edge-impulse-sdk/CMSIS/NN/Source/ConvolutionFunctions/arm_convolve_wrapper_s8.c
A	week2/action-recog-applab/cpp_server/edge-impulse-sdk/CMSIS/NN/Source/ConvolutionFunctions/arm_depthwise_conv_3x3_s8.c
A	week2/action-recog-applab/cpp_server/edge-impulse-sdk/CMSIS/NN/Source/ConvolutionFunctions/arm_depthwise_conv_fast_s16.c
A	week2/action-recog-applab/cpp_server/edge-impulse-sdk/CMSIS/NN/Source/ConvolutionFunctions/arm_depthwise_conv_s16.c
A	week2/action-recog-applab/cpp_server/edge-impulse-sdk/CMSIS/NN/Source/ConvolutionFunctions/arm_depthwise_conv_s8.c
A	week2/action-recog-applab/cpp_server/edge-impulse-sdk/CMSIS/NN/Source/ConvolutionFunctions/arm_depthwise_conv_s8_opt.c
A	week2/action-recog-applab/cpp_server/edge-impulse-sdk/CMSIS/NN/Source/ConvolutionFunctions/arm_depthwise_conv_u8_basic_ver1.c
A	week2/action-recog-applab/cpp_server/edge-impulse-sdk/CMSIS/NN/Source/ConvolutionFunctions/arm_depthwise_conv_wrapper_s16.c
A	week2/action-recog-applab/cpp_server/edge-impulse-sdk/CMSIS/NN/Source/ConvolutionFunctions/arm_depthwise_conv_wrapper_s8.c
A	week2/action-recog-applab/cpp_server/edge-impulse-sdk/CMSIS/NN/Source/ConvolutionFunctions/arm_depthwise_separable_conv_HWC_q7.c
A	week2/action-recog-applab/cpp_server/edge-impulse-sdk/CMSIS/NN/Source/ConvolutionFunctions/arm_depthwise_separable_conv_HWC_q7_nonsquare.c
A	week2/action-recog-applab/cpp_server/edge-impulse-sdk/CMSIS/NN/Source/ConvolutionFunctions/arm_nn_depthwise_conv_s8_core.c
A	week2/action-recog-applab/cpp_server/edge-impulse-sdk/CMSIS/NN/Source/ConvolutionFunctions/arm_nn_mat_mult_kernel_q7_q15.c
A	week2/action-recog-applab/cpp_server/edge-impulse-sdk/CMSIS/NN/Source/ConvolutionFunctions/arm_nn_mat_mult_kernel_q7_q15_reordered.c
A	week2/action-recog-applab/cpp_server/edge-impulse-sdk/CMSIS/NN/Source/ConvolutionFunctions/arm_nn_mat_mult_kernel_s8_s16.c
A	week2/action-recog-applab/cpp_server/edge-impulse-sdk/CMSIS/NN/Source/ConvolutionFunctions/arm_nn_mat_mult_s8.c
A	week2/action-recog-applab/cpp_server/edge-impulse-sdk/CMSIS/NN/Source/FullyConnectedFunctions/arm_fully_connected_mat_q7_vec_q15.c
A	week2/action-recog-applab/cpp_server/edge-impulse-sdk/CMSIS/NN/Source/FullyConnectedFunctions/arm_fully_connected_mat_q7_vec_q15_opt.c
A	week2/action-recog-applab/cpp_server/edge-impulse-sdk/CMSIS/NN/Source/FullyConnectedFunctions/arm_fully_connected_q15.c
A	week2/action-recog-applab/cpp_server/edge-impulse-sdk/CMSIS/NN/Source/FullyConnectedFunctions/arm_fully_connected_q15_opt.c
A	week2/action-recog-applab/cpp_server/edge-impulse-sdk/CMSIS/NN/Source/FullyConnectedFunctions/arm_fully_connected_q7.c
A	week2/action-recog-applab/cpp_server/edge-impulse-sdk/CMSIS/NN/Source/FullyConnectedFunctions/arm_fully_connected_q7_opt.c
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

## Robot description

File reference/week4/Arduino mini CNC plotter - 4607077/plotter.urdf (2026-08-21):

<?xml version="1.0"?>
<robot name="mini_cnc_plotter">

  <material name="purple">
    <color rgba="0.5 0.0 0.5 1.0"/>
  </material>

  <link name="base_link">
    <visual>
      <origin xyz="0 0 0" rpy="0 0 0" />
      <geometry>
        <mesh filename="files/1.stl" scale="0.001 0.001 0.001" />
      </geometry>
      <material name="purple"/>
    </visual>
    <collision>
      <origin xyz="0 0 0" rpy="0 0 0" />
      <geometry>
        <mesh filename="files/1.stl" scale="0.001 0.001 0.001" />
      </geometry>
    </collision>
    <visual>
      <origin xyz="0 0 0" rpy="0 0 0" />
      <geometry>
        <mesh filename="files/5.stl" scale="0.001 0.001 0.001" />
      </geometry>
      <material name="purple"/>
    </visual>
    <collision>
      <origin xyz="0 0 0" rpy="0 0 0" />
      <geometry>
        <mesh filename="files/5.stl" scale="0.001 0.001 0.001" />
      </geometry>
    </collision>
    <visual>
      <origin xyz="0 0 0" rpy="0 0 0" />
      <geometry>
        <mesh filename="files/6.stl" scale="0.001 0.001 0.001" />
      </geometry>
      <material name="purple"/>
    </visual>
    <collision>
      <origin xyz="0 0 0" rpy="0 0 0" />
      <geometry>
        <mesh filename="files/6.stl" scale="0.001 0.001 0.001" />
      </geometry>
    </collision>
    <visual>
      <origin xyz="0 0 0" rpy="0 0 0" />
      <geometry>
        <mesh filename="files/7.stl" scale="0.001 0.001 0.001" />
      </geometry>
      <material name="purple"/>
    </visual>
    <collision>
      <origin xyz="0 0 0" rpy="0 0 0" />
      <geometry>
        <mesh filename="files/7.stl" scale="0.001 0.001 0.001" />
      </geometry>
    </collision>
    <visual>
      <origin xyz="0 0 0" rpy="0 0 0" />
      <geometry>
        <mesh filename="files/8.stl" scale="0.001 0.001 0.001" />
      </geometry>
      <material name="purple"/>
    </visual>
    <collision>
      <origin xyz="0 0 0" rpy="0 0 0" />
      <geometry>
        <mesh filename="files/8.stl" scale="0.001 0.001 0.001" />
      </geometry>
    </collision>
    <visual>
      <origin xyz="0 0 0" rpy="0 0 0" />
      <geometry>
        <mesh filename="files/9.stl" scale="0.001 0.001 0.001" />
      </geometry>
      <material name="purple"/>
    </visual>
    <collision>
      <origin xyz="0 0 0" rpy="0 0 0" />
      <geometry>
        <mesh filename="files/9.stl" scale="0.001 0.001 0.001" />
      </geometry>
    </collision>
    <visual>
      <origin xyz="0 0 0" rpy="0 0 0" />
      <geometry>
        <mesh filename="files/A.stl" scale="0.001 0.001 0.001" />
      </geometry>
      <material name="purple"/>
    </visual>
    <collision>
      <origin xyz="0 0 0" rpy="0 0 0" />
      <geometry>
        <mesh filename="files/A.stl" scale="0.001 0.001 0.001" />
      </geometry>
    </collision>
    <visual>
      <origin xyz="0 0 0" rpy="0 0 0" />
      <geometry>
        <mesh filename="files/B.stl" scale="0.001 0.001 0.001" />
      </geometry>
      <material name="purple"/>
    </visual>
    <collision>
      <origin xyz="0 0 0" rpy="0 0 0" />
      <geometry>
        <mesh filename="files/B.stl" scale="0.001 0.001 0.001" />
      </geometry>
    </collision>
    <visual>
      <origin xyz="0 0 0" rpy="0 0 0" />
      <geometry>
        <mesh filename="files/Arduino_mini_CNC_plotter-N1.stl" scale="0.001 0.001 0.001" />
      </geometry>
      <material name="purple"/>
    </visual>
    <collision>
      <origin xyz="0 0 0" rpy="0 0 0" />
      <geometry>
        <mesh filename="files/Arduino_mini_CNC_plotter-N1.stl" scale="0.001 0.001 0.001" />
      </geometry>
    </collision>
  </link>

  <link name="y_axis">
    <visual>
      <geometry>
        <mesh filename="files/2.stl" scale="0.001 0.001 0.001" />
      </geometry>
      <material name="purple"/>
    </visual>
    <collision>
      <geometry>
        <mesh filename="files/2.stl" scale="0.001 0.001 0.001" />
      </geometry>
    </collision>
  </link>

  <joint name="y_joint" type="prismatic">
    <parent link="base_link"/>
    <child link="y_axis"/>
    <origin xyz="0 0 0.05" rpy="0 0 0"/>
    <axis xyz="0 1 0"/>
    <limit lower="-0.05" upper="0.05" effort="10" velocity="0.1"/>
  </joint>

  <link name="x_axis">
    <visual>
      <geometry>
        <mesh filename="files/3.stl" scale="0.001 0.001 0.001" />
      </geometry>
      <material name="purple"/>
    </visual>
    <collision>
      <geometry>
        <mesh filename="files/3.stl" scale="0.001 0.001 0.001" />
      </geometry>
    </collision>
  </link>

  <joint name="x_joint" type="prismatic">
    <parent link="y_axis"/>
    <child link="x_axis"/>
    <origin xyz="0 0 0.02" rpy="0 0 0"/>
    <axis xyz="1 0 0"/>
    <limit lower="-0.05" upper="0.05" effort="10" velocity="0.1"/>
  </joint>

  <link name="z_axis">
    <visual>
      <geometry>
        <mesh filename="files/4.stl" scale="0.001 0.001 0.001" />
      </geometry>
      <material name="purple"/>
    </visual>
    <collision>
      <geometry>
        <mesh filename="files/4.stl" scale="0.001 0.001 0.001" />
      </geometry>
    </collision>
  </link>

  <joint name="z_joint" type="prismatic">
    <parent link="x_axis"/>
    <child link="z_axis"/>
    <origin xyz="0 0 0.02" rpy="0 0 0"/>
    <axis xyz="0 0 1"/>
    <limit lower="-0.02" upper="0.02" effort="10" velocity="0.1"/>
  </joint>

</robot>

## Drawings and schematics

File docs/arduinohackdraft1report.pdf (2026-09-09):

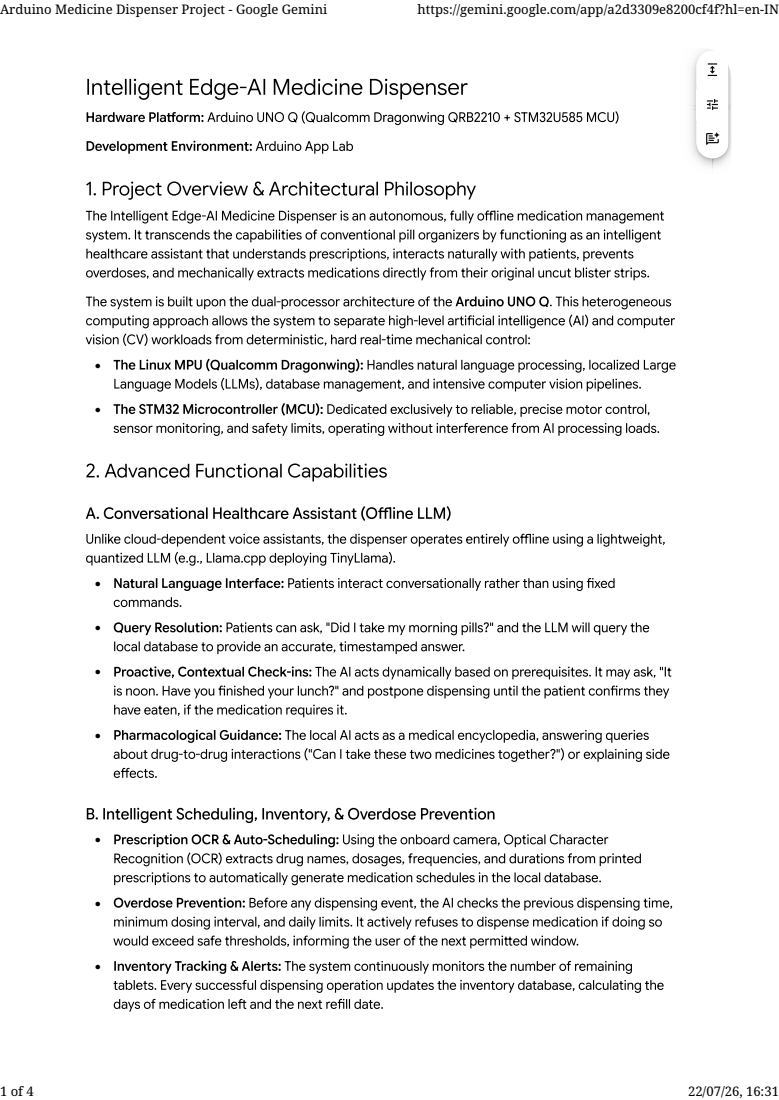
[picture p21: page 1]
Arduino Medicine Dispenser Project - Google Gemini; https://gemini.google.com/app/a2d3309e8200cf4f?hl=en-IN

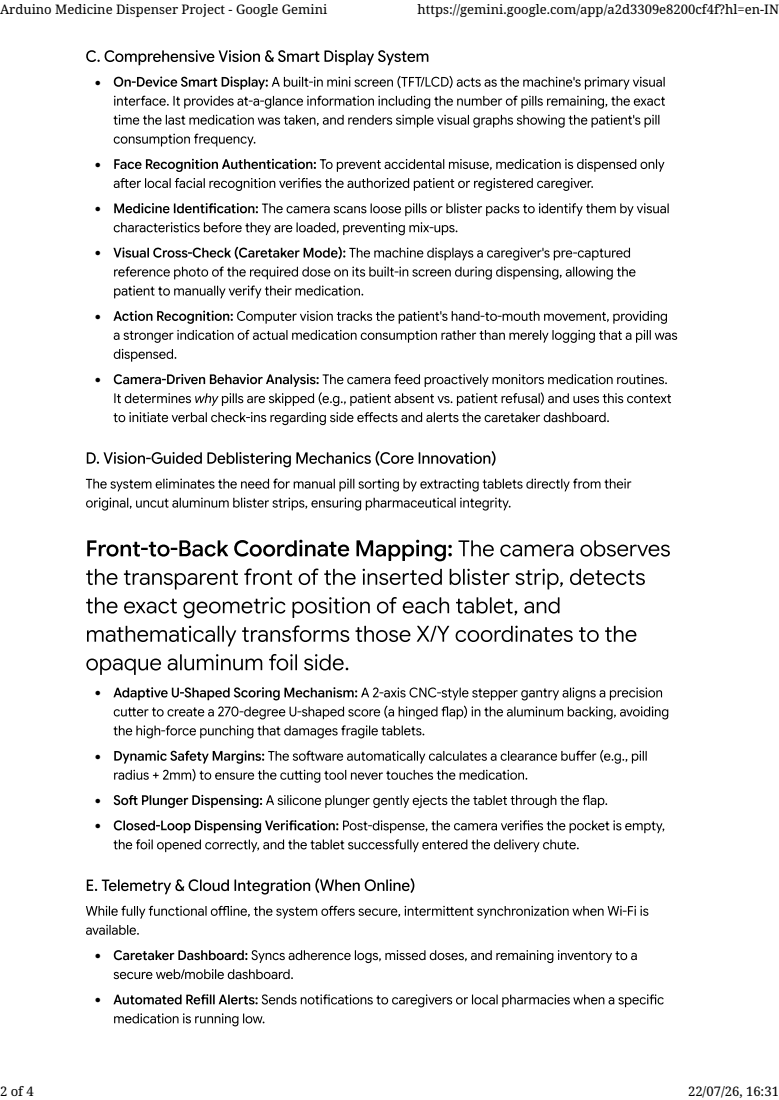
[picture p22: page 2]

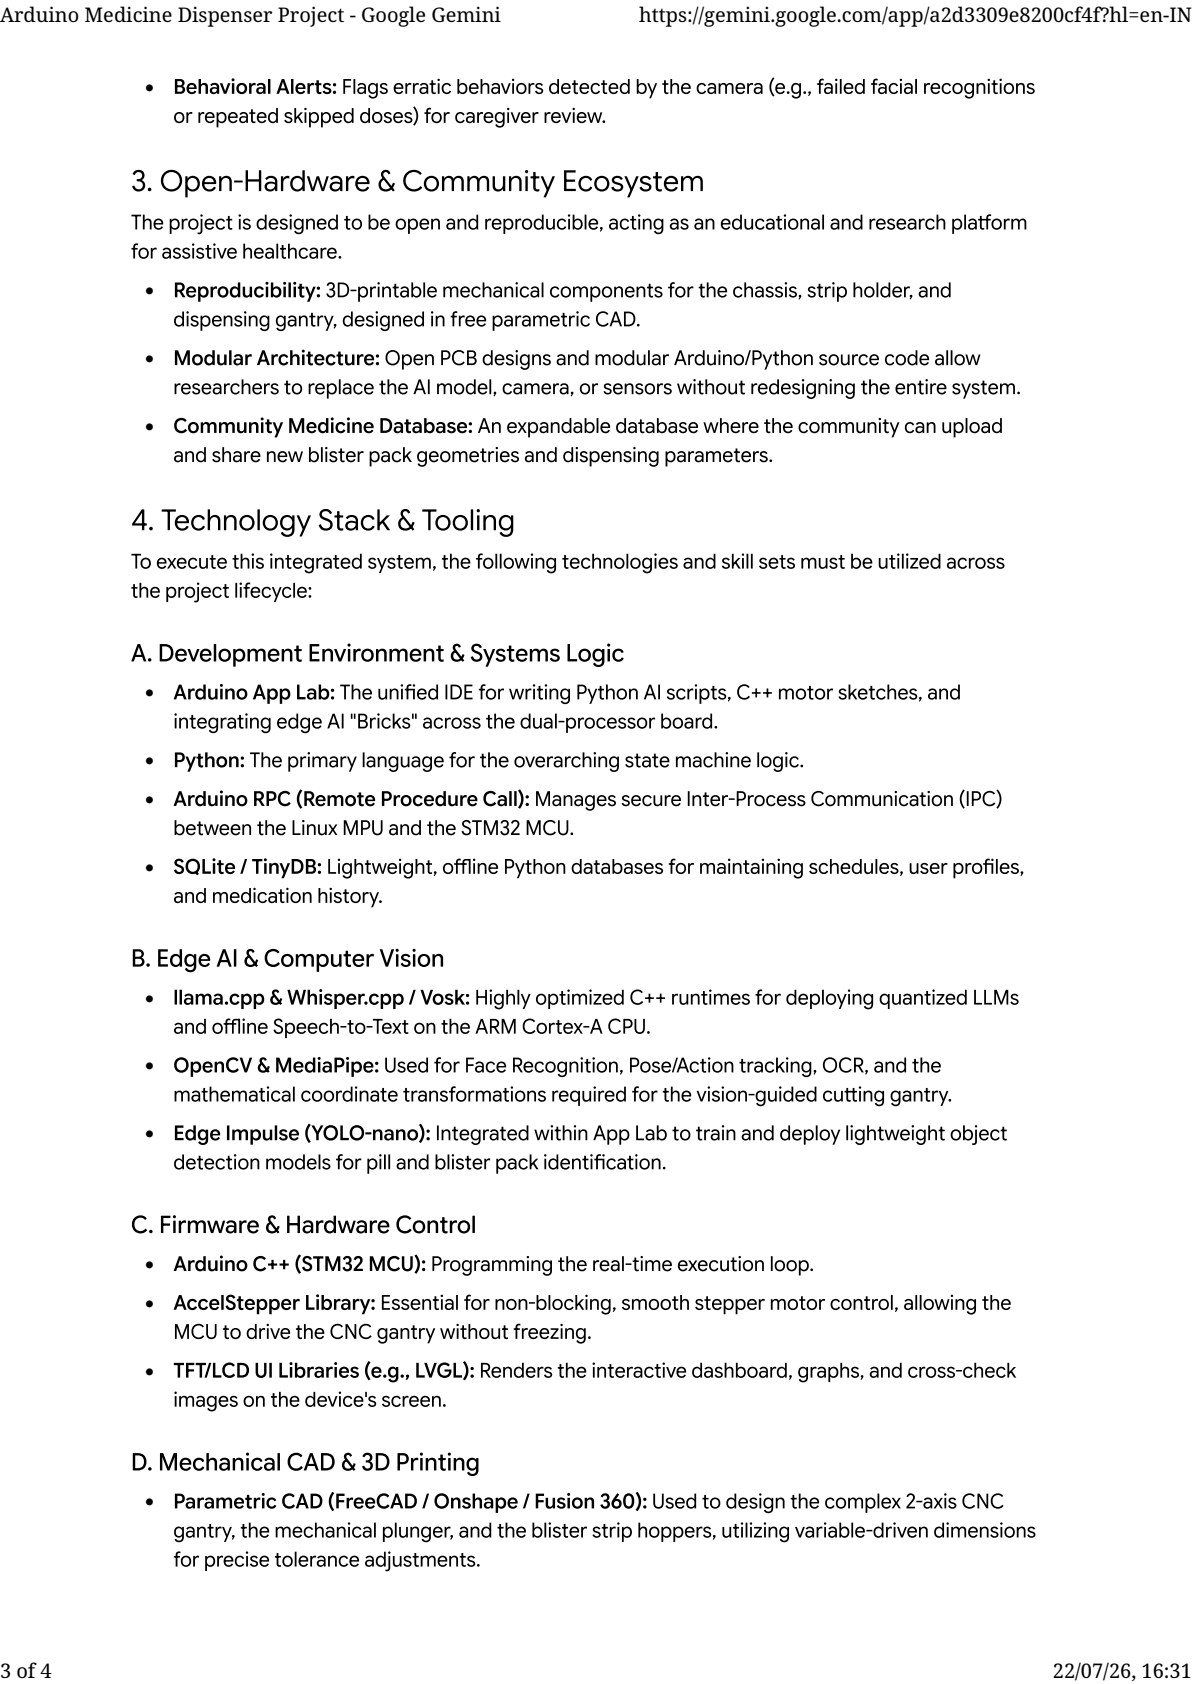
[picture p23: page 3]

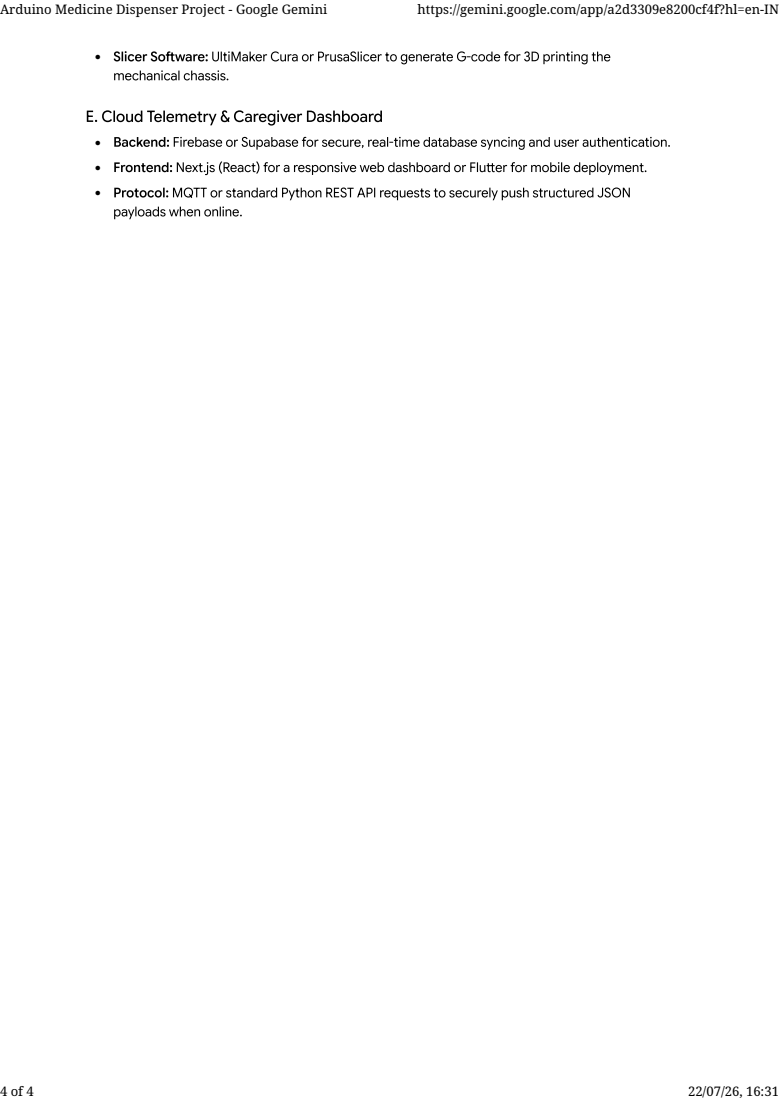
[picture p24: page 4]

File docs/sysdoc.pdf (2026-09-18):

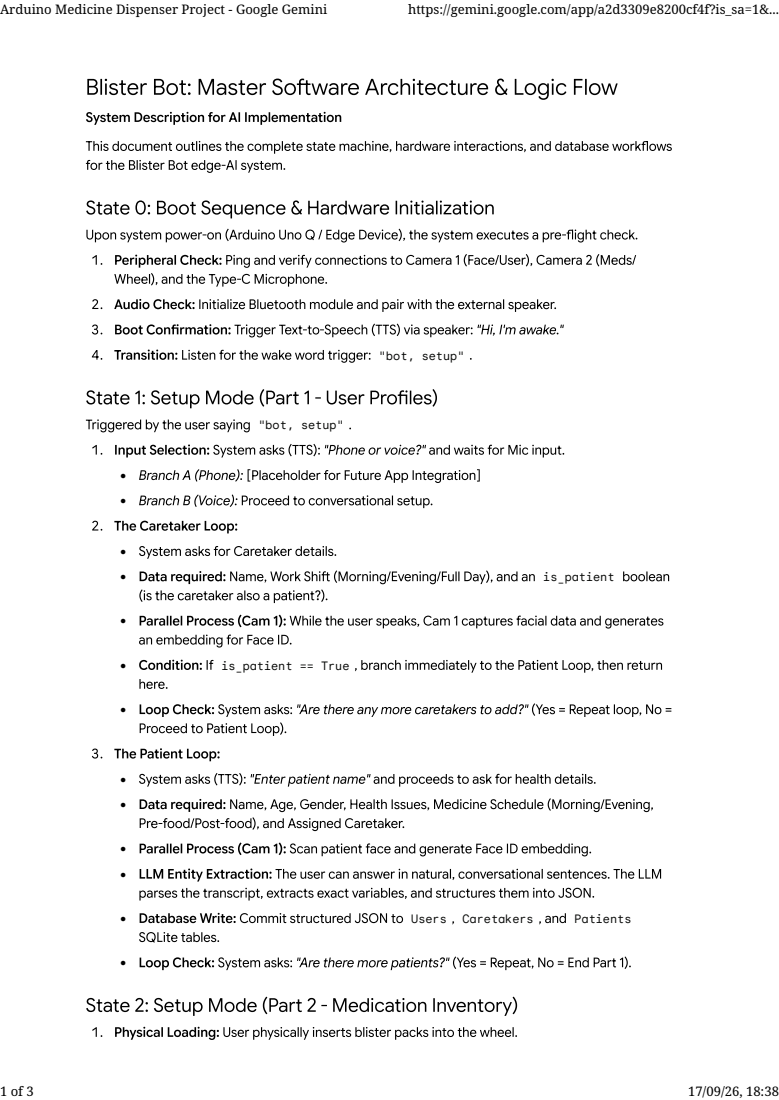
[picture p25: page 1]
"bot, setup"; • • is_patient; • is_patient == True; Users; Caretakers; Patients; Arduino Medicine Dispenser Project - Google Gemini; https://gemini.google.com/app/a2d3309e8200cf4f?is_sa=1&...

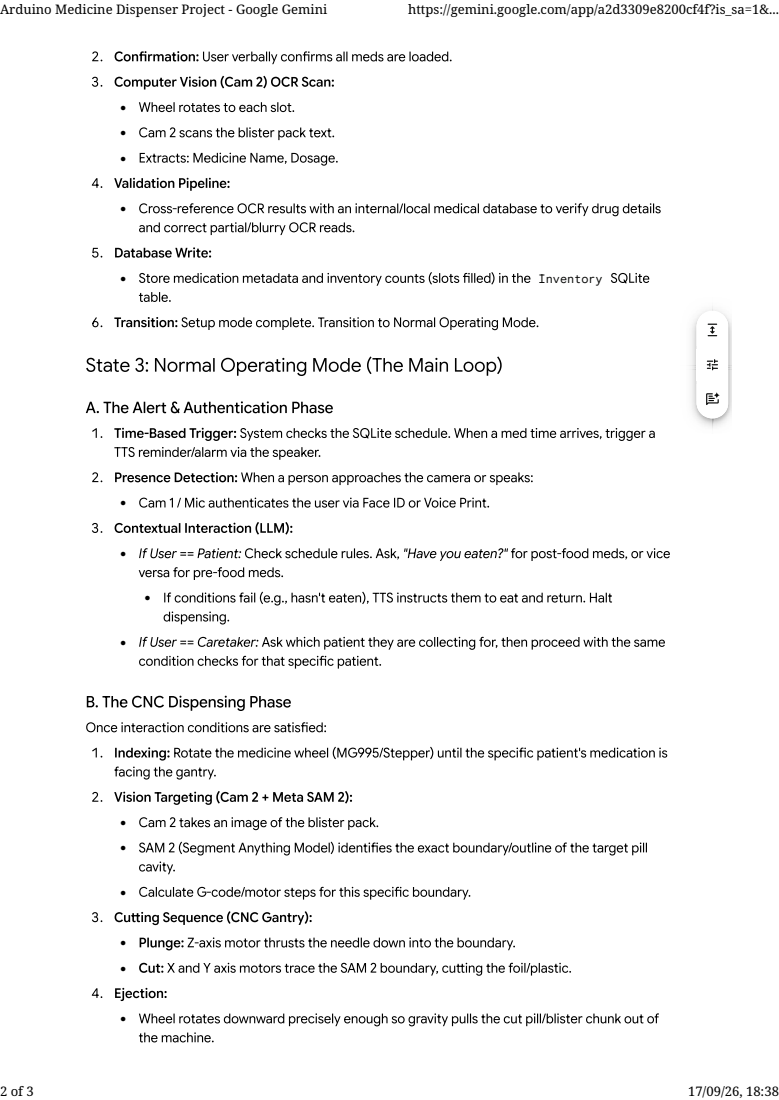
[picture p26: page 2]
• Inventory

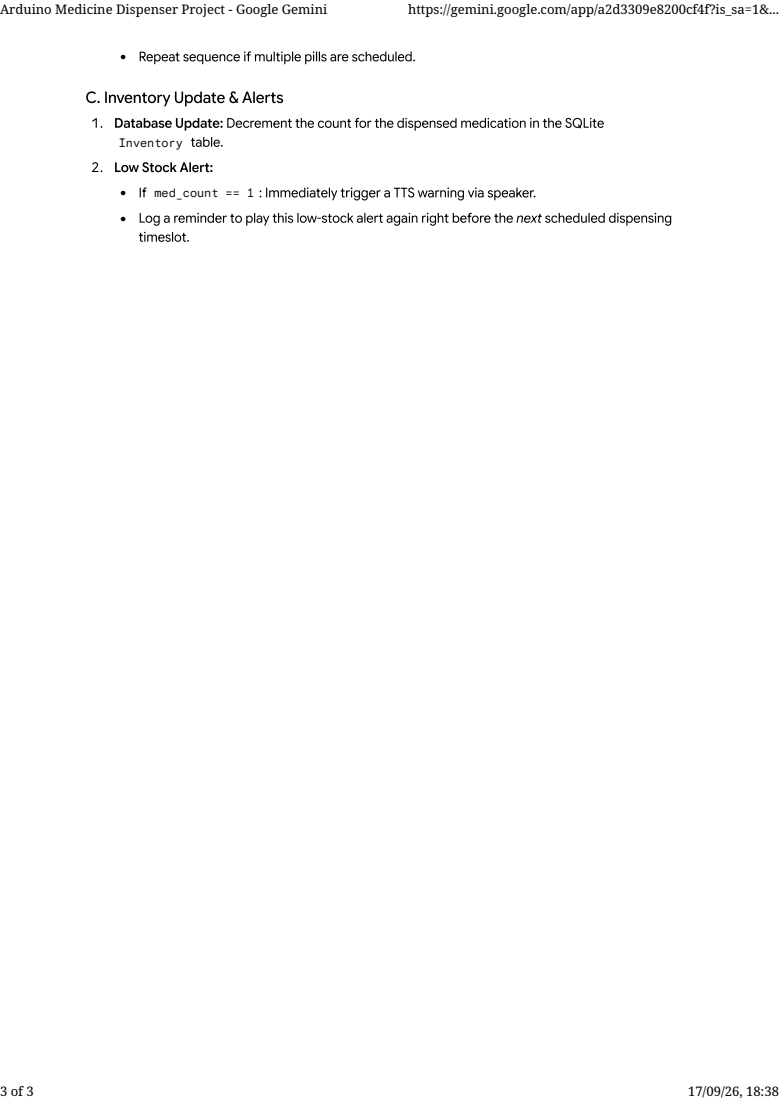
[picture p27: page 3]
Inventory; • med_count == 1

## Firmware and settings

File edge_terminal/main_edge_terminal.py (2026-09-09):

import os
import sys
import time
import tempfile
import serial
import sounddevice as sd
from scipy.io import wavfile
import torch
from transformers import AutoModelForSpeechSeq2Seq, AutoProcessor, pipeline

# Import local modules
sys.path.append(os.path.abspath(os.path.join(os.path.dirname(__file__), 'Blister-bot-main-', 'week2', 'edge_agent')))
from edge_agent import load_model, run_agent

# --- Audio Config ---
FS = 16000  # Whisper prefers 16kHz
DURATION = 5  # Record for 5 seconds

# --- App Lab Serial Bridge Config ---
# The bridge between the Linux side and the STM32 MCU
BRIDGE_PORT = '/dev/ttyGS0'
BRIDGE_BAUD = 115200

def init_bridge():
    try:
        bridge = serial.Serial(BRIDGE_PORT, BRIDGE_BAUD, timeout=1)
        time.sleep(2) # Wait for MCU to reset/connect
        return bridge
    except Exception as e:
        print(f"[WARNING] Could not connect to MCU via {BRIDGE_PORT}: {e}")
        return None

def send_to_lcd(bridge, text):
    """Sends text over the serial bridge to the Arduino sketch to be printed on the LCD."""
    print(f"\n[LCD Output]:\n{text}")
    if bridge:
        # Sanitize newlines for the simple serial protocol
        clean_text = text.replace('\n', ' ')
        command = f"PRINT:{clean_text}\n"
        bridge.write(command.encode('utf-8'))
        
        # Wait for acknowledgment
        start_time = time.time()
        while time.time() - start_time < 2:
            if bridge.in_waiting:
                response = bridge.readline().decode('utf-8').strip()
                if response == "ACK:PRINT_DONE":
                    break
            time.sleep(0.01)

def load_whisper():
    print("[INFO] Loading Whisper Tiny (Edge Optimized)...")
    device = "cuda:0" if torch.cuda.is_available() else "cpu"
    torch_dtype = torch.float16 if torch.cuda.is_available() else torch.float32

    model_id = "openai/whisper-tiny.en"
    model = AutoModelForSpeechSeq2Seq.from_pretrained(
        model_id, torch_dtype=torch_dtype, low_cpu_mem_usage=True, use_safetensors=True
    )
    model.to(device)

    processor = AutoProcessor.from_pretrained(model_id)

    pipe = pipeline(
        "automatic-speech-recognition",
        model=model,
        tokenizer=processor.tokenizer,
        feature_extractor=processor.feature_extractor,
        torch_dtype=torch_dtype,
        device=device,
    )
    return pipe

def record_audio_chunk():
    """Records audio from the USB microphone for a fixed duration."""
    input("\n🎤 Press [ENTER] to start speaking for 5 seconds...")
    print("[RECORDING] Speak now...")
    recording = sd.rec(int(DURATION * FS), samplerate=FS, channels=1, dtype='int16')
    sd.wait()  # Wait until recording is finished
    print("[DONE] Processing audio...")
    
    # Save to temp file
    temp_wav = tempfile.mktemp(suffix=".wav")
    wavfile.write(temp_wav, FS, recording)
    return temp_wav

def main():
    # Initialize the App Lab Serial Bridge to the Microcontroller
    bridge = init_bridge()
    send_to_lcd(bridge, "Booting AI Terminal...")
    
    # Load Models
    whisper_pipe = load_whisper()
    send_to_lcd(bridge, "Whisper Loaded. Loading LLM...")
    
    # Load LLM from the week2 folder
    os.chdir(os.path.join(os.path.dirname(__file__), 'Blister-bot-main-', 'week2', 'edge_agent'))
    llm = load_model()
    
    send_to_lcd(bridge, "System Ready. Press ENTER to speak.")
    print("\n" + "="*50)
    print("Edge-AI Terminal Ready. Awaiting Voice Input.")
    print("="*50)
    
    while True:
        try:
            # 1. Listen (Record Audio)
            audio_path = record_audio_chunk()
            
            # 2. Transcribe
            send_to_lcd(bridge, "Listening... Transcribing...")
            result = whisper_pipe(
                audio_path,
                generate_kwargs={
                    "condition_on_prev_tokens": False,
                    "temperature": (0.0,),
                }
            )
            os.unlink(audio_path)
            
            user_text = result.get("text", "").strip()
            if not user_text:
                print("[INFO] No speech detected.")
                send_to_lcd(bridge, "No speech detected. Press ENTER to speak.")
                continue
                
            print(f"[User Said]: {user_text}")
            send_to_lcd(bridge, f"User: {user_text} ...Thinking...")
            
            # 3. Process Intent via Local LLM (edge_agent)
            response_text = run_agent(llm, user_text)
            
            # 4. Display Output to the MCU driven LCD
            send_to_lcd(bridge, response_text)
            
        except KeyboardInterrupt:
            print("\nShutting down terminal...")
            send_to_lcd(bridge, "System Offline.")
            if bridge:
                bridge.close()
            break
        except Exception as e:
            print(f"[ERROR]: {e}")
            send_to_lcd(bridge, f"Error: {str(e)}")

if __name__ == "__main__":
    main()

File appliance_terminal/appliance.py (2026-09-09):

import cv2
import serial
import os
import time
import numpy as np
import threading
from flask import Flask, Response
from rapidocr_onnxruntime import RapidOCR
import re
import glob

ocr = RapidOCR()

app = Flask(__name__)

# Globals for streams
output_frame = None
output_frame_ocr = None
lock = threading.Lock()
last_ocr_text = "Waiting for scan..."
active_mode = "face"  # can be "face" or "ocr"
force_ocr = False

# Voice Globals
stt_pipe = None
is_recording = False

def init_stt():
    global stt_pipe
    print("[INFO] Loading STT (Whisper) model in background...", flush=True)
    try:
        from faster_whisper import WhisperModel
        stt_pipe = WhisperModel("tiny.en", device="cpu", compute_type="int8")
        print("[INFO] STT model loaded successfully.", flush=True)
    except Exception as e:
        print(f"[ERROR] Failed to load STT model: {e}")

threading.Thread(target=init_stt, daemon=True).start()

def speak_text(text):
    def _speak():
        print(f"[TTS] Speaking: {text}")
        # Use edge-tts to generate speech and ffplay to play it immediately
        os.system(f"/home/arduino/.local/bin/edge-tts --text '{text}' --write-media /tmp/speech.mp3 && ffplay -nodisp -autoexit /tmp/speech.mp3 >/dev/null 2>&1")
    threading.Thread(target=_speak, daemon=True).start()

def record_and_transcribe():
    global is_recording, stt_pipe, last_ocr_text
    if is_recording or stt_pipe is None:
        return
    is_recording = True
    
    def _worker():
        global is_recording, last_ocr_text
        print("[MIC] Recording for 5 seconds...", flush=True)
        # Record audio from the USB microphone via ALSA using plughw for auto-resampling
        os.system("arecord -D plughw:0,0 -f S16_LE -c1 -r 16000 -d 5 /tmp/capture.wav >/dev/null 2>&1")
        print("[MIC] Recording finished. Transcribing...", flush=True)
        try:
            segments, info = stt_pipe.transcribe("/tmp/capture.wav", beam_size=1)
            transcript = " ".join([segment.text for segment in segments]).strip()
            print(f"[STT] User said: {transcript}")
            if transcript:
                last_ocr_text = f"You said: {transcript}"
                speak_text(f"You said: {transcript}")
        except Exception as e:
            print(f"[ERROR] STT failed: {e}")
        is_recording = False

    threading.Thread(target=_worker, daemon=True).start()

# Face Recognition Globals
face_cascade = cv2.CascadeClassifier(cv2.data.haarcascades + 'haarcascade_frontalface_default.xml')
recognizer = cv2.face.LBPHFaceRecognizer_create()
KNOWN_FACES_DIR = "known_faces"

def load_known_faces():
    print("[INFO] Loading known faces...", flush=True)
    id_to_name = {}
    faces = []
    ids = []
    
    if not os.path.exists(KNOWN_FACES_DIR):
        print("[WARNING] No known_faces directory found.")
        return id_to_name
        
    for person_name in os.listdir(KNOWN_FACES_DIR):
        person_dir = os.path.join(KNOWN_FACES_DIR, person_name)
        if not os.path.isdir(person_dir):
            continue
            
        person_id = len(id_to_name)
        id_to_name[person_id] = person_name
        
        for image_path in glob.glob(os.path.join(person_dir, "*.jpg")):
            img = cv2.imread(image_path, cv2.IMREAD_GRAYSCALE)
            if img is not None:
                faces.append(img)
                ids.append(person_id)
                
    if len(faces) > 0:
        recognizer.train(faces, np.array(ids))
        print(f"[INFO] Trained {len(faces)} images for {len(id_to_name)} people.", flush=True)
    else:
        print("[WARNING] No images found to train.")
        
    return id_to_name

def init_bridge():
    try:
        bridge = serial.Serial('/dev/ttyGS0', 115200, timeout=1, write_timeout=0.1)
        print("[INFO] Opened /dev/ttyGS0")
        return bridge
    except Exception as e:
        print(f"[ERROR] Could not open /dev/ttyGS0: {e}")
        return None

import difflib

def extract_patterns(text):
    patterns = {
        'medicine': None,
        'dosage': None,
    }
    
    medicine_keywords = ['PARACETAMOL', 'AMOXICILLIN', 'IBUPROFEN', 'ASPIRIN', 'CETIRIZINE', 'LIPITOR']
    text_upper = text.upper()
    
    for keyword in medicine_keywords:
        if keyword in text_upper:
            patterns['medicine'] = keyword
            break
            
    if not patterns['medicine']:
        words = text_upper.split()
        for word in words:
            clean_word = re.sub(r'[^A-Z]', '', word)
            if len(clean_word) >= 5:
                matches = difflib.get_close_matches(clean_word, medicine_keywords, n=1, cutoff=0.7)
                if matches:
                    patterns['medicine'] = matches[0]
                    break
            
    dosage_match = re.search(r'(\d+)\s*(MG|ML)', text, re.IGNORECASE)
    if dosage_match:
        patterns['dosage'] = dosage_match.group(0).upper()
        
    return patterns

def generate_face_video():
    global output_frame, lock
    while True:
        with lock:
            if output_frame is None:
                continue
            (flag, encodedImage) = cv2.imencode(".jpg", output_frame)
            if not flag:
                continue
        yield(b'--frame\r\n' b'Content-Type: image/jpeg\r\n\r\n' + 
              bytearray(encodedImage) + b'\r\n')

def generate_ocr_video():
    global output_frame_ocr, lock
    while True:
        with lock:
            if output_frame_ocr is None:
                continue
            (flag, encodedImage) = cv2.imencode(".jpg", output_frame_ocr)
            if not flag:
                continue
        yield(b'--frame\r\n' b'Content-Type: image/jpeg\r\n\r\n' + 
              bytearray(encodedImage) + b'\r\n')
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

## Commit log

2026-08-01 experiment with blender and stripping mechanism
    [blister_bot.blend, scoring_mechanism.blend, vertical_scoring_mechanism.blend]
2026-08-01 My CAD-Scoring thoughts for week 1
2026-08-15 arduino work
2026-08-21 Add Week 2 OCR evaluation module and pipeline analysis
    [1.stl, 2.stl, 3.stl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]
2026-08-22 add different ocr models
    [ocr_benchmark_results.csv]
2026-09-12 Organize repository structure and add stepper motor web controller
2026-09-12 Update connections.md with breadboard and driver details
2026-09-12 Update connections.md to explicitly mention 6V 4xAA battery pack
2026-09-12 added stl file
    [new3d.stl]
2026-09-12 added another stl file
    [new3d1.stl]
2026-09-16 added medicine wheel stand stl file
    [medicinewheelstand.stl]
2026-09-17 last support stand
    [blissupport.stl]
2026-09-17 Combine week1 documentation and summaries into week1.md
    [Unnamed7.FCStd]
2026-09-17 clean up repo phase 1
    [blister_bot.blend, scoring_mechanism.blend, vertical_scoring_mechanism.blend]
2026-09-17 moved around some files
    [blissupport.stl, medicinewheelstand.stl, new3d.stl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]
2026-09-18 Organize repository structure strictly by chronological timeline and extract final code/cad
    [1.stl, 2.stl, 3.stl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]
2026-10-06 docs: Reformat and expand README in Circuit Digest style with component table and media placeholders
2026-10-11 docs: Add Mermaid.js architecture, state machine, and kinematics diagrams
2026-10-11 docs: Add detailed circuit, dual interface, mirror math, and pipeline Mermaid diagrams
2026-10-11 docs: Add hardware prototype images, detailed engineering specs, and master doc
2026-10-11 docs: Update motor architecture to 3x L293D drivers without buck converter and add CNC moving trial video
2026-10-11 docs: Add sample AI-based CAD prompts for medicine holder rotor and stand
